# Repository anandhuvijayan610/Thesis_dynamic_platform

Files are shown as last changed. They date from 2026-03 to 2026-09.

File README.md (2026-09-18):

# Dynamic Platform — a camera-guided ball balancing and juggling robot

A four-arm parallel platform that balances and juggles a 40 mm ball. A camera **underneath a
transparent plate** tracks the ball, a PC works out the plate tilt and height that bring it back to
the target, and a Teensy 4.0 turns that pose into step pulses for four geared stepper motors.

Built for a thesis at Deggendorf Institute of Technology, Campus Cham, on top of Tobias Kuhn's
open-source [HighPrecisionStepperJuggler](https://github.com/T-Kuhn/HighPrecisionStepperJuggler).

## Demo

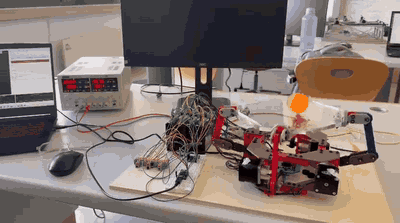
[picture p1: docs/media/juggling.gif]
The machine juggling: the plate throws the ball and catches it, cycle after cycle


**Juggling.** The plate throws the ball and catches it, over and over.

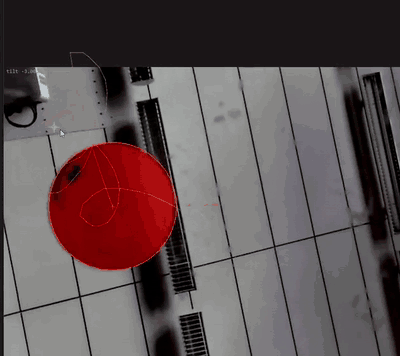
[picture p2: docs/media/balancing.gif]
The camera's view of the plate with the ball tracked in red and the green cross marking the commanded position


**Holding a target.** What the camera under the plate sees. The ball is outlined in red and the
**green cross is the commanded position** — the loop keeps the ball on it. Clicking the video in the
app moves the target.

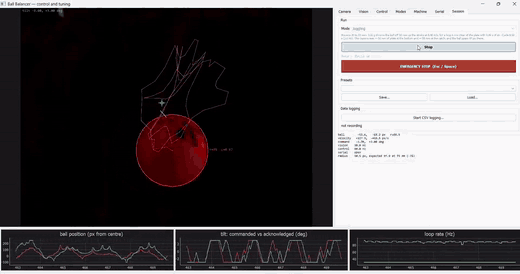
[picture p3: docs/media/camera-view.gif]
The control window during a juggle, with live plots of ball position, tilt and loop rate


**Juggling from the camera view.** The same juggle inside the control app, with the live plots
running: ball position, commanded versus acknowledged tilt, and loop rate.

## Run the demo

You need the machine powered up, the camera plugged in, and the
[firmware](docs/firmware.md) already on the Teensy. Note the Teensy's COM port first.

### The quick way — PyQt5 app

```bash
cd pyballbalancer
pip install -r requirements.txt
python main.py
```

Then, in the window:

1. **Serial** tab → *Refresh ports* → pick the `COMx` → *Connect*
2. **Machine** tab → *Go to ORIGIN* — the plate should rise and sit level
3. Place the ball on the plate
4. **Session** tab → choose **Balancing** → *Start control*

Try **Juggling** on the Session tab once balancing holds. Click the video to move the target.

- **Stop:** `Esc` or `Space`, or the red button.
- **Close the window normally** rather than killing the process — closing parks the plate level. If
  the plate is left leaning, run `python park.py`.

### The other way — Unity app

Open the project in **Unity 2019.2.23f1**, load
`Assets/HighPrecisionStepperJuggler/MainScene.unity`, set the serial port and strategy program in
the Inspector, press **Play**, then **Space** to arm. Full steps: [docs/unity-app.md](docs/unity-app.md).

## Two hosts, one machine

There are **two separate programs** that can drive this machine, and they share only the hardware
and the firmware:

| | [PyQt5 app](pyballbalancer/README.md) | [Unity app](docs/unity-app.md) |
|---|---|---|
| Language | Python 3 | C# (Unity 2019.2.23f1) + a C++ OpenCV plugin |
| Camera frame | 640 × 480 landscape | 480 × 640 portrait |
| Gain units | degrees per **pixel** | degrees per **millimetre** |
| Tuning | live, from GUI tabs | Inspector values in the scene |

**Do not copy tuning from one to the other.** Different frame orientations, different units,
different calibration — the same number means something else in each. Only one of them can hold the
serial port, so close one before starting the other.

## Documentation

| Page | What is in it |
|---|---|
| [docs/hardware.md](docs/hardware.md) | Parts, wiring, DM542T switch settings, power |
| [docs/firmware.md](docs/firmware.md) | Uploading to the Teensy, the wire protocol, key constants |
| [pyballbalancer/README.md](pyballbalancer/README.md) | The PyQt5 app in full: modes, calibration, tuning, every script |
| [docs/unity-app.md](docs/unity-app.md) | Unity setup, strategy programs, keyboard controls, calibration |
| [docs/camera-and-motion.md](docs/camera-and-motion.md) | Why the camera's field of view limits the design, and the throw physics |
| [docs/troubleshooting.md](docs/troubleshooting.md) | Known issues, traps, and what to check when nothing moves |
| [docs/repository.md](docs/repository.md) | Folder layout, Git LFS notes, thesis tooling |

## Licence and credits

Firmware, Unity application, camera plugin and the original paper are by **Tobias Kuhn** — see
[HighPrecisionStepperJuggler](https://github.com/T-Kuhn/HighPrecisionStepperJuggler) and the related
[Octo-Bouncer](https://www.electrondust.com/2020/03/01/the-octo-bouncer/), MIT licence
([LICENSE](HighPrecisionStepperJuggler-master/LICENSE)).

The hardware rebuild, firmware fixes, Unity extensions, the PyQt5 application and all calibration in
this repository are by **Anandhu Vijayan**.

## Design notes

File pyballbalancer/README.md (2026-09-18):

# Ball Balancer — PyQt5 control application

*One of the two host applications in this project. See the
[main README](../README.md) for the machine as a whole, and
[docs/hardware.md](../docs/hardware.md) / [docs/firmware.md](../docs/firmware.md) for what this
talks to. The Unity host is separate: **do not copy tuning between them**.*

A replacement for the Unity host application: camera capture, ball detection,
tilt control, serial link to the microcontroller, and live tuning of every
parameter without restarting.

```
pip install -r requirements.txt
python main.py
```

## Modules

| file | responsibility |
|---|---|
| `params.py` | every tunable value, declared once in `SPECS`; the GUI is generated from it |
| `camera.py` | `CameraWorker` — capture thread, applies UVC controls, runs detection |
| `vision.py` | two interchangeable detectors, both returning centre-frame coordinates |
| `control.py` | velocity estimation, PID, mirror-law tilt, the fixed-rate `ControlLoop` |
| `serial_io.py` | `SerialWorker` — owns the port, coalesces writes, applies the level trim, parses telemetry |
| `machine.py` | kinematics: plate pose → four arm angles → the firmware's wire format |
| `machine_panel.py` | the Machine tab: manual moves, levelling at the working height, bring-up tests |
| `modes.py` | the session modes and juggling supervision; owns height, move time and cadence |
| `optics.py` | camera window and throw physics, validated against the rig |
| `datalog.py` | buffered CSV recorder |
| `widgets.py` | parameter editors and the video view |
| `gui.py` | `MainWindow` — assembles panels, owns the workers, routes signals |
| `main.py` | entry point |

Threads: capture, control and serial each own one. The GUI thread only paints.
Anything crossing a thread boundary goes through a Qt signal, except the
parameter store, which is guarded by a lock because both worker threads read it.

## The firmware protocol

The Teensy runs the SineStepper sketch, and its protocol is not a command
language. Each line is colon-separated doubles, six per move batch, with up to
100 batches concatenated:

```
PC  -> MCU   <marker>:<a0>:<a1>:<a2>:<a3>:<move_time>
             PING
MCU -> PC    PONG
```

`marker` is `11.0 x batch_number`, counting from one, and a batch whose marker
does not match is skipped. `a0..a3` are the four arm angles in **radians**, as
a **difference from the origin pose**, because the firmware treats its power-on
position as zero. `move_time` is in seconds and is clamped up to a 0.05 s floor.

There is no `HOME` and no `STOP`. Levelling and the emergency stop are both a
move to the origin pose — the safe state has to be commanded, not requested.
`PING` is the exception: it is answered with `PONG` before the line reaches the
parser, so it is the only liveness check available.

`machine.py` turns a plate pose — height in metres, two tilts in degrees — into
those four angles, and `machine.serialize()` builds the line. Nothing else in
the application knows the wire format.

**A malformed line fails silently.** The firmware's `strtok`/`atof` parse yields
zero batches and it does nothing at all, so a protocol mismatch is
indistinguishable from dead motors. If the plate will not move, PING first.

**Pose commands are coalesced.** If the control loop outruns the port, only the
newest pose is sent. A stale tilt is worse than none, and a growing backlog
would show up as the plate lagging the ball by a variable amount.

## If the plate looks tilted

The motors hold whatever pose they were last given. Anything that stops without
tidying up — a diagnostic script that ends mid-sequence, a window that is killed
rather than closed — leaves the plate at the last tilt the control loop asked
for. It looks exactly like the levelling trim having drifted, and it is not.

```
python park.py
```

That commands the calibrated level origin and prints the line it sent beside the
line an untrimmed plate would get. The trim is working if the four arm angles
differ from each other; if all four are identical, the trim has been lost.
**Close the window rather than killing it** — `closeEvent` parks the plate on
the way out, and a force-kill skips it.

## Settled calibration

These are on this machine, found by adjustment until the ball sits still in the
middle of the plate and does not roll:

```
arm pairing     0+2 / 1+3                 motors confirmed opposite by eye
working origin  20 mm above the mechanical dead position
level trim      X -0.40, Y -0.40 degrees, levelled at 35 mm (mac_trim_height)
axis mapping    swap/invertX/invertY all off
gains           kp 0.02  ki 0.10  kd 0.04 per axis,  integral clamp 20,
                scaled with ball radius (reference radius 111 px)
limits          max tilt 3 deg, max tilt rate 25 deg/s, command rate 100 Hz
camera          exposure -8, gain 120
detection       H 0..20, S>=150, V>=15, kernel 7, min fill 0.80, min circularity 0.30
```

The trim and gains have been re-found more than once as the rig changed: an
earlier set (trim X -1.30 / Y +0.35, kp 0.05 / kd 0.07) predates levelling at
the working height and is superseded. The values above are the shipped defaults
in `params.py`.

Two things about the trim are easy to get wrong. It is **per pairing** --
changing which motor each tilt drives invalidates it -- and it is **per
height**: these differ by about 1.5 degrees from the values a spirit level
gives at the origin, because the linkage carries a residual slope between the
origin and the 40 mm the controller runs at. Levelling at the origin is not
enough; the definition that matters is where the ball stays.

The integral term is what removes that slope, and `pid_i_clamp` is the part
that makes it possible: it bounds the tilt the integral may ask for at
`Ki x clamp`. At the old clamp of 2.0 that ceiling was 0.2 degrees with
Ki=0.1, far short of the degree or so a real slope needs, so raising Ki alone
achieved nothing. Simulated against a 1.4 degree slope, ki=0 leaves 28 mm of
standing offset and ki=0.1 with clamp 20 leaves none, halving the peak
excursion as well. Ki=0.8 is unstable, so there is plenty of margin.

**Adjusting until the ball stays beats measuring the slope and correcting it.**
Measuring it from the ball's drift open-loop was not reproducible here: the
same trim read `(+334, +748)` on one run and `(-677, -710)` on the next, sign
flipped on both axes, because the ball is placed by hand and is still moving
when the reading starts. Fitting acceleration instead of velocity removes the
dependence on that initial speed and is exact without noise, but over the short
arc the ball survives it is far too noisy to act on.

## Levelling the plate

The plate does not sit level when all four arms are at their origin — arm
length tolerances and how the joints seated during assembly leave a standing
tilt, on this rig along the X pair. `mac_trim_x` and `mac_trim_y` cancel it.

Set them from the Machine tab, with a spirit level on the plate: the nudge
buttons move the trim and immediately re-send the origin pose, so the plate is
adjusted by eye. Do X first — tilting one pair changes how level the other
looks. The offset is then added to *every* commanded tilt, the control loop's
included, so a level plate here means the controller's zero is the real zero
rather than a standing bias it has to fight.

It is applied in exactly one place: `SerialWorker`, the funnel every wire-bound
pose passes through. Several call sites build poses — the Machine panel, the
mode runner, the emergency stop — and applying it at each would eventually miss
one or double it somewhere.

**It is deliberately not folded into `ORIGIN_ANGLES`.** `serialize()` subtracts
that constant from every target, so a trim added there too would cancel itself
out and the plate would never move. The Unity host documents the same trap for
its own origin offset.

**Level where the loop works, not at the origin.** The linkage carries a
residual slope that changes along its travel, so the trim is a property of the
*height* as much as of the machine -- here the two differ by about 1.5 degrees
between the origin and the working height. The nudge buttons therefore send the
plate to `mac_trim_height` (35 mm above the working origin by default) and
adjust it there, rather than at the origin. A spirit level gets you close; the
definition that matters is that the ball stays put at that height. See
**Settled calibration** above for the shipped values.

Measured on the rig, the origin pose at several trims:

```
trim X      a0       a1       a2       a3
+0.00    0.11941  0.11941  0.11941  0.11941
+0.50    0.13462  0.10415  0.11941  0.11941
+1.00    0.14978  0.08884  0.11941  0.11941
-1.00    0.08884  0.14978  0.11941  0.11941
```

The X pair splits, the Y pair is untouched, and the two directions mirror.

## Exposure decides detection

The single most important setting for detection is the camera exposure, not
the colour gate. Measured on this rig at exposure -6 with gain 110, **55% of
the ball was clipped to pure white** -- V=255, saturation 0, hue meaningless.
There is no colour left in a clipped pixel, so no threshold can recover it: the
mask became a crescent of the ball's shaded side, and the centre of that
crescent sat **35 px (7 mm) away from the ball's true centre**, consistently,
in the direction of the highlight. A steady bias like that does not average
out; the controller simply chases the wrong place.

Widening the gate cannot fix it, and the sweep says so plainly -- every
combination of hue and saturation gave 35-36 px. Nor can geometry: fitting a
circle to the crescent's boundary (algebraic and RANSAC both tried) reached
28.7 px at best, because the mask was eroded all round rather than merely cut
on one side.

At exposure **-8 with gain 60** nothing clips, and the numbers change
completely:

| | before | after |
|---|---|---|
| median centre error | 35.2 px (7.2 mm) | **0.8 px (0.2 mm)** |
| radius reported | 90 px, true 139 | 97 px, true 100 |
| frame-to-frame jitter | - | 1.1 px |
| live detection rate | 94% | 40 of 40 |

*(The shipped camera setting is now exposure -8 with gain 120, and the value
floor has since been lowered to `V>=15` with a 7 px kernel and a fill gate -- a
floor of 50 was cutting away the ball's shaded half. The measurement above is
kept because it is the evidence for the principle.)*

The gate that suits that image is `H 0..20, S>=150, V>=50`. **Saturation is what
separates ball from background**, and it can be that strict only because the
ball is no longer blown out: 95% of its pixels sit at S=255 while the ceiling
is grey. Value cannot do the separating -- the background reaches V=110 and the
ball starts at V=101 -- which is why the value floor is deliberately loose and
only rejects sensor noise.

**So check for clipping before touching the colour gate.** If the ball's
histogram piles up at V=255, the exposure is the fault and everything
downstream is guesswork.

## Which blob is the ball

A single frame cannot say. A ball whose lit side falls outside the colour gate
breaks into several contours, and background clutter can be rounder than any of
them. `BallTracker` uses continuity between frames instead:

- **Plate region.** Candidates further than `vis_roi_radius` from frame centre
  are discarded outright. The ball is on the plate and the plate is centred, so
  this is the strongest geometric evidence available, and the ball's centre has
  far less travel than that before it clips the frame edge anyway.
- **Trust is earned.** A new candidate must hold within `vis_lock_tol_px` for
  `vis_lock_frames` consecutive frames before it is believed. Until then the
  answer is "no ball", which every caller already treats as wait-and-do-nothing.
- **Then tracked by proximity**, within `vis_gate_px` of the last accepted
  position, with the lock dropped after `vis_gate_frames` consecutive misses so
  a ball that is picked up and put back somewhere else is found again.

The cold-start rule is the subtle one: it picks the candidate nearest the
centre of the plate, **not** the largest. Taking the largest is what latches
onto background, and once latched the proximity gate defends that choice
forever, because something that never moves always looks like the same thing,
still nearby. The lock has to be earned before it is trusted, not assumed and
then defended.

Detection is therefore stateful, and one frame can never produce a ball. Call
`VisionProcessor.reset()` when a run starts; the GUI does this on arming so a
lock earned while idle is not inherited.

**Tune the colour gate on a frame captured through this application**, not on a
raw `cv2.VideoCapture` grab. The app pushes saturation, contrast and gain into
the camera, and those move the whole scene: on a raw capture a plain ceiling
sits well below the saturation floor, while through the app the same ceiling
reaches a median of 64. A gate tuned on the wrong image looks fine in the
measurement and admits half the background in use.

## Which way does the plate push the ball

If a commanded tilt moves the ball the wrong way the loop accelerates it
outward instead of catching it, and the ball leaves every time — which reads as
gains being wrong, or the plate being too aggressive, rather than as a mapping
fault. `ctl_swap_axes`, `ctl_invert_x` and `ctl_invert_y` describe the mapping;
there are eight combinations and trying them by hand costs a ball roll each.

```
python signtest.py            measure and report
python signtest.py --apply    and write the result into the parameters
```

It tilts ±2 deg on each axis and measures the ball's response. Three details
are what make it work on a plate with no rim:

- **Velocity, not position.** Under a constant tilt the ball accelerates, so
  where it ends up after a fixed time depends on where it started. How fast it
  is moving does not.
- **Both directions, differenced.** A plate slightly off level, or a ball
  already drifting, adds the same bias to the + and - legs; subtracting them
  cancels it. A single leg measures the bias as much as the response.
- **A centimetre of travel per leg**, and each tilt is unwound by the opposite
  one for twice as long, which brings the ball back near rest.

It also reports the angle between the two response directions. That must be
near 90 deg: if the two tilt commands act on nearly the same physical
direction, no swap or invert can express the mapping and the fault is the motor
pairing (`machine.MOTOR_ORDER`) instead.

**The plate has no rim, and that is the practical obstacle.** A cardboard
collar or a tape lip around the edge makes this measurement and every tuning
step after it straightforward. Without one the ball may leave mid-measurement —
the tool says so rather than reporting a guess.

## Modes

Five, picked on the Session tab; the numbers live on the Modes tab.

| mode | what it does |
|---|---|
| **Balancing** | holds the ball at the balancing height, indefinitely |
| **Balance then rest** | holds it lively for a while, then softens the gains so it slows and stops in the middle |
| **Balance and juggle** | holds it centred, and throws a hop every few seconds |
| **Juggling** | bounces continuously, four phases per cycle (35 → 51 mm by default) |
| **Juggle routine** | a structured sequence modelled on the Unity host's Full Juggling Demo: warm-up bounces, then walking the target out and back and tracing a small circle, with settling cycles between legs |

### Juggling is supervised

The camera's window is narrow, so a drifting ball is lost long before the plate
runs out of travel. Both juggling modes therefore treat "centred" as something
to keep earning:

- **Throwing only starts** once the ball is within `mod_jug_centre_px` (40 px)
  and slower than `mod_jug_centre_speed` (120 px/s) for `mod_jug_centre_hold`
  (8) consecutive commands.
- **Throwing stops** and the plate falls back to balancing whenever the ball
  drifts beyond `mod_jug_keep_mm` (30 mm) or is unseen for
  `mod_jug_lost_seconds` (0.4 s). The routine also resets its target to the
  centre.
- **While re-centring, the rest gains are swapped in**, which bring the ball in
  faster than the lively juggling gains.
- **If the plate was at the top of a stroke, it comes down over the fall time.**
  Dropping 16 mm in a short balancing move is about 2 g, which pulls the plate
  out from under the ball and throws it again.

### Sizing a hop

**Commanded acceleration does not predict whether the ball leaves the plate on
this machine.** Measured: 30 mm in 0.10 s (1.51 g) separates it, while 20 mm in
0.08 s -- a *higher* 1.57 g -- does not. The short stroke gives the motors too
little time to reach the speed being asked for, so they under-deliver. If the
ball is not leaving the plate, go **bigger and slower**, not faster.

30 mm in 0.10 s is the smallest proven hop, leaving at 0.47 m/s for an 11 mm hop
with about 0.10 s of air; the shipped *Balance and juggle* default is now a
larger 50 mm in 0.11 s (`mod_hop_mm`, `mod_hop_rise`). The plate then holds still at the top for
that airborne time, so the ball lands on a stationary surface rather than a
moving one, and returns down twice as slowly -- the fall throws nothing, so
speed there is only shaking the frame.

**Tilt stays live through every phase, the airborne one included.** The plate
has to be in the right place when the ball comes down, and levelling during the
hop throws away exactly the correction that would put it there.

The Session tab picks a mode and starts it; the Modes tab holds the numbers.

**Balancing** rises once to `mod_balance_height` (30 mm above the working
origin by default) over `mod_rise_time`, waits `mod_settle_time`, then holds
that height and issues a tilt every `mod_balance_move_time`. No tilt is applied
during the climb: the ball has nothing useful to say while the platform is
still moving vertically, and correcting against a rising plate only fights it.

**Juggling** runs a four-phase cycle at that height: a fast rise that throws the
ball, a dwell while it is airborne, a deliberately slower fall, and a dwell at
the bottom. Only the rise needs to beat 1 g; the fall launches nothing, so
speed there is structural excitation for no benefit, and the dwells let the
frame stop ringing between strokes. The panel reports the rise's peak in g, and
says plainly when it is too gentle to lift the ball off the plate. Tilt is
corrected on every phase, including the fall and the bottom dwell, because
those are when the ball is in contact and can actually be rolled toward centre.

**A long move is sent once and then left alone.** The firmware clears its
queued batches and restarts on every line it receives, and each move is a
half-cosine that begins at rest -- so re-sending the same target every control
tick restarts the profile from zero velocity and the plate crawls upward at a
few mm/s while the log looks perfectly healthy. `ModeRunner.command()` returns
`None` to mean "a move is still running, do not interrupt it". That is why the
mode owns the cadence rather than the control loop.

Arming requires an open port. Without one the loop would run and the mode would
advance through its phases with nothing reaching a machine.

## When it looks like nothing is happening

The firmware is built with `VERBOSE_SERIAL_LOGGING` set to `0`. It answers
`PING` with `PONG`, prints a rejection for a batch whose marker is wrong, and
**says nothing else at all** — not for a move it accepted, not for a line it
could not parse. A healthy link is therefore almost entirely silent, and an
empty monitor is the normal state rather than a symptom.

Two scripts settle it without guessing. Nothing else may hold the port while
they run — Windows allows one owner, so close the GUI first:

```
python hwtest.py            bare pyserial: is the board alive?
python hwtest.py --move     ... and does it move?
python workertest.py        the same, through the app's own SerialWorker
python workertest.py --move
```

`hwtest.py` sends a deliberately bad marker, which is the one malformed input
the firmware does complain about — a reply proves the parser is running and
reading our fields, not merely that the cable is plugged in. If `hwtest` passes
and `workertest` fails, the fault is in the application; if both pass and the
plate still does not move, it is past the microcontroller: driver enable, motor
power, or the DM542T wiring.

## Bringing the machine up

The *Machine* tab exists because a control loop cannot be debugged before the
three things under it are known to work, in this order:

1. **Go to ORIGIN** — level, at the working origin. The plate at rest has no
   downward travel -- and the structure interferes near the bottom -- so the
   working origin is parked 20 mm above it (`mac_origin_offset`) to give the
   loop room to move either way.
2. **Height, no tilt** — a pure vertical move proves all four arms are driven,
   wired the same way round, and agree with each other. If the plate skews, the
   fault is mechanical or in `MOTOR_ORDER`, not in the control maths.
3. **Tilt** — one axis at a time, then the sweep. If both axes tip the plate the
   same physical way, `MOTOR_ORDER` in `machine.py` pairs the arms wrongly.

Every button prints the line it sent and the per-motor angle and pulse count
behind it, so a plate that does not move can be diagnosed as bad numbers or bad
motors without reaching for a scope.

## First run

1. **Camera** tab — set the device index. If the picture is dark, raise Gain
   before lengthening Exposure: a long exposure smears a moving ball, and
   motion blur costs more than noise does.
2. **Vision** tab — tick *Show mask* and adjust the HSV range until the ball is
   solid white and nothing else is. Tune with the mask visible; tuning against
   the colour image is guesswork. Untick it when you are done.
3. **Serial** tab — *Refresh ports*, pick the `COMx`, *Connect*. Telemetry
   should start scrolling if the firmware is sending it.
4. **Control** tab — set *Max tilt* low (2–3°) for the first run.
5. **Session** tab — *Start control*. Click the video to move the target.

### Getting the axis signs right

The camera's axes almost never match the plate's first time. With the ball
resting off-centre and the loop running, watch which way the plate moves. Use
*Swap axes*, *Invert X* and *Invert Y* until a ball sitting to the right makes
the plate lift on the right. If the ball accelerates away instead of returning,
a sign is wrong — no amount of gain tuning fixes that, and raising the gain
makes it leave the plate faster.

## Tuning the controller

Start from `Kd`, not `Kp`. A ball on a plate is a double integrator with a
transport delay, and such a plant needs the derivative term to be stable at
all; proportional-only control oscillates with growing amplitude no matter how
small the gain. `simtest.py` demonstrates both cases.

Measured behaviour of an earlier gain pair (`Kp` 0.05, `Kd` 0.07) against the
simulated plant -- the shipped defaults are now softer (0.02 / 0.04), but the
delay trend is the lesson and still holds:

| loop delay | result |
|---|---|
| 15–100 ms | settles, no overshoot |
| 150 ms | still settles, but rings noticeably |
| 200 ms and up | does not settle — re-derive the gains |

The *control* trace on the rate plot is the number that matters here. If it
falls, the delay rises and the gains that were right become wrong.

## Emergency stop

`Esc` or `Space`, or the red button. It disarms the loop, commands 0° and
commands the plate level at the working origin in the shortest move the
firmware accepts. Re-arming with *Start control* clears it. Closing the window
levels the plate before the process exits.

## Tests

```
python selftest.py    # parameters, velocity estimation, PID, mirror law, vision, logging
python machinetest.py # kinematics and the wire format
python modetest.py    # the mode state machine, against an injected clock
python guitest.py     # the real window offscreen: threads, and every button clicked
python simtest.py     # closed-loop simulation against a modelled ball and plate
```

`selftest` and `simtest` need no hardware; `guitest` runs headless. All three
exit non-zero on failure, so they can be wired into a pre-commit hook.

## Every script, at a glance

The application itself is `main.py` plus the modules listed at the top. Everything else is a tool
that does one job, run from this folder. The hardware ones need the serial port to themselves, so
close the GUI first.

| Script | Purpose | Hardware? |
|---|---|---|
| `selftest.py` · `machinetest.py` · `modetest.py` · `simtest.py` | Parameters, vision, kinematics, wire format, mode state machine, closed-loop simulation | no |
| `guitest.py` | Builds the real window offscreen and clicks every button | no |
| `optics.py` | Camera window and throw physics model (also importable) | no |
| `hwtest.py` · `workertest.py` | Is the board alive, and does it move? `--move` also moves the plate | yes |
| `park.py` | Put the plate back on the calibrated level origin | yes |
| `movetest.py` | Presses the Machine tab's buttons for real | yes |
| `signtest.py` · `mappingsearch.py` · `pairingtest.py` | Which way the plate pushes the ball; the axis mapping; which arms pair | yes |
| `autolevel.py` · `centretrim.py` · `backlashtest.py` | Levelling and play, using the ball as the instrument | yes |
| `exposuretest.py` · `heighttest.py` | Exposure that measures the ball at true size; visibility when raised | yes |
| `livetest.py` | The oscillation, with the whole GUI alive around it | yes |
| `unitycheck.py` | Confirms the two hosts agree on **hardware** facts only; reports tuning side by side without judging it | no |

## Notes on two defaults that are not obvious

**`vis_hough_p2` is 16, not the more usual 32.** The transform runs on the
binary mask, whose thinned edges cast far fewer accumulator votes than a grey
image's would. Measured on synthetic balls from 10 to 160 px radius, 32 finds
nothing at any size while 16 finds all of them with no false positives.

**Detection runs on the capture thread, not its own.** The control loop wants
the newest ball position, not every position. Queueing frames to a second
worker would add latency and a backlog to drain. Display is throttled to about
30 Hz independently, so the screen never limits the control rate.

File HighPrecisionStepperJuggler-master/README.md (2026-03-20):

The Arduino folder contains the code for the Teensy 4.0. The Teensy 4.0's job is simple:

- Listen for movement comments on the serial bus
- Generate pulses for the stepper motors

The Unity folder contains the code for the Unity Application. This Application is responsible for:

- Set up the camera (120 FPS 640×480 data stream, gain, exposure, contrast, ISO, saturation) via OpenCV
- Set up Camera Device and getting image stream via OpenCV
- Run Image Processing and get 2D pixel position of ping pong ball
- Get 3D position of ping pong ball using the results of above-mentioned image processing
- Calculate ball velocity
- Use ball position and velocity in PID/Analytical control code to calculate correction-tilt of plate
- Execute Inverse Kinematic code to figure out how much each motor needs to rotate in order to get the plate to a certain height with a     specific tilt.
- Send result of IK calculation to the microcontroller via serial interface
- Render machine position and movements
- Render image processing data
- Render graph showing several data streams

The UVCCameraPlugin folder contains the C++ code for the camera plugin. This is a Unity plugin. All the OpenCV code is being executed in here.

# Important
You need to download openCV 4.2 and get the `opencv_world420.dll` from the build folder and put it inside Plugins/UVC Camera Plugin next to `UVCCameraPlugin.dll`. If you don't do that you'll get below error message on play:

```
Plugins: Failed to load 'Assets/Plugins/UVC Camera Plugin/UVCCameraPlugin.dll' because one or more of its dependencies could not be loaded.
```

Also, you need to use Unity Editor version 2019.2.6f1. It won't run with newer versions.

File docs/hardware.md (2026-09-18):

# Hardware setup

### Parts

| Part | Detail |
|---|---|
| Microcontroller | Teensy 4.0 |
| Stepper drivers | 4 × StepperOnline **DM542T** |
| Motors | 4 × NEMA17 **17HS19-1684S-PG5** — 1.8°/step, **5.18:1** planetary gearbox, 1.68 A/phase |
| Power | 35 V / 8 A supply; **XL4016** buck converter for the 5 V rail |
| Linkage | 4 arms, `L1 = 89 mm`, `L2 = 80 mm`, plate joints 299 mm apart, `Q = 70.023 mm` |
| Camera | UVC USB camera, 60.41° horizontal FOV, mounted **below** a transparent plate |
| Ball | 40 mm diameter (radius 20 mm) |

Datasheets for all of these are in [`datasheets/`](../datasheets/); CAD is in [`Design/`](../Design/)
and [`stl files/`](../stl%20files/).

### Wiring (Teensy → DM542T)

The finalised, working connection diagram:

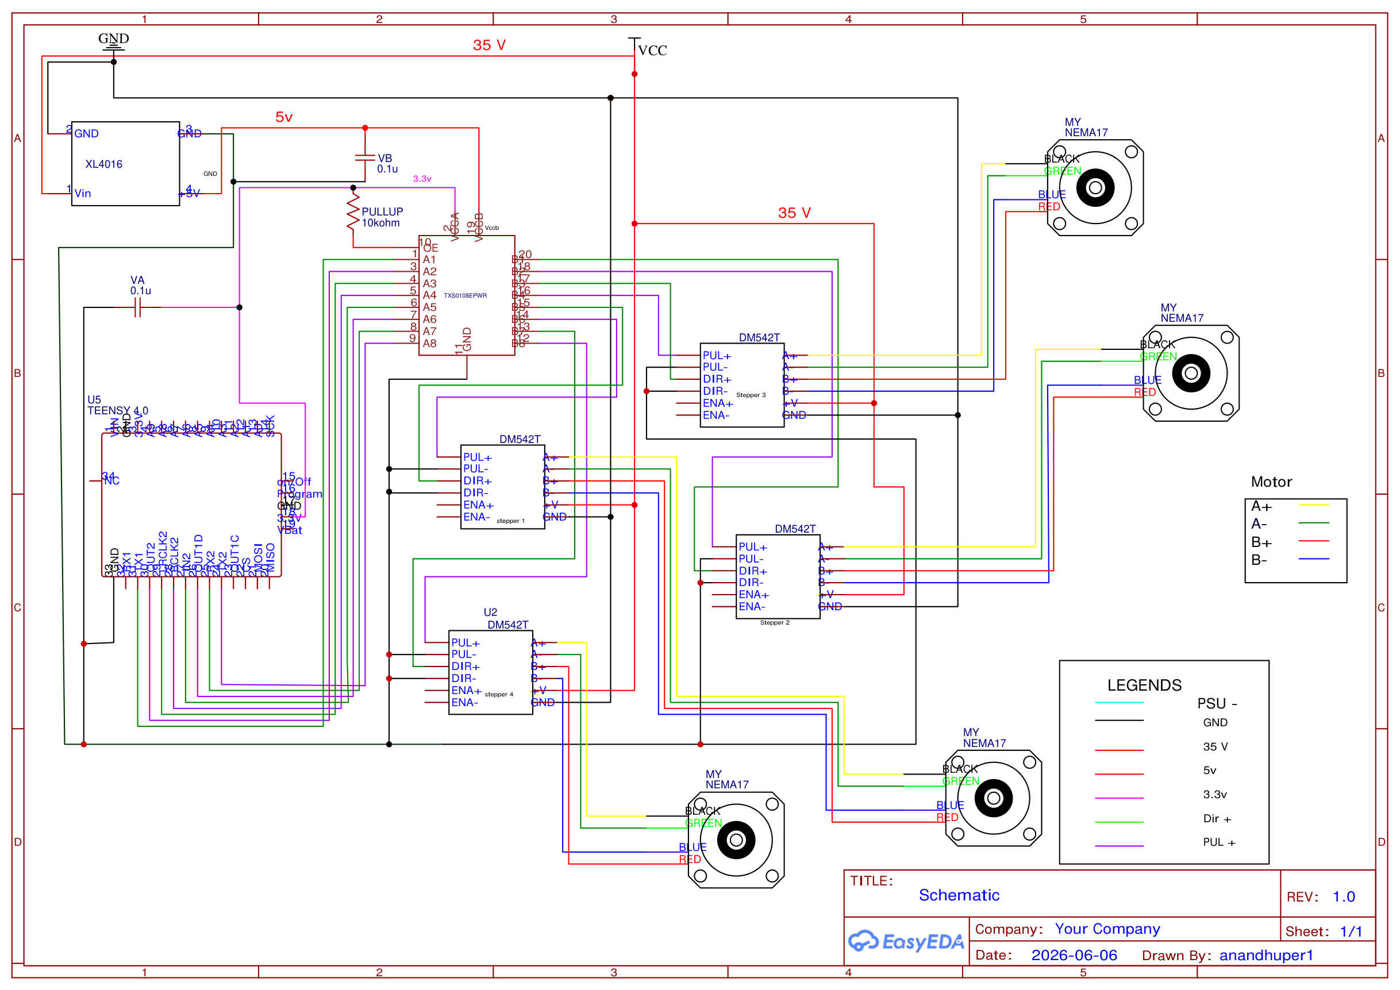
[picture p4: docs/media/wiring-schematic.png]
Finalised wiring schematic: Teensy 4.0 through a TXS0108E level shifter to four DM542T drivers and four NEMA17 motors, with an XL4016 buck converter making the 5 V rail


*Click for the vector PDF ([media/wiring-schematic.pdf](media/wiring-schematic.pdf)). Drawn in
EasyEDA; the source is also kept in
[`my_documents/connection diagrams/`](../my_documents/connection%20diagrams/).*

Reading it: the main rail feeds all four `DM542T` `+V` inputs and an **XL4016** buck converter that
makes **5 V**; the **TXS0108E** shifts the Teensy's eight STEP/DIR lines up to that 5 V rail
(`VCCA` 3.3 V, `VCCB` 5 V, `OE` held high through a 10 kΩ pull-up, 0.1 µF on each supply). Motor
coils follow the legend — **A+ yellow, A− green, B+ red, B− blue**.

Pin numbers are fixed in the firmware's `Constants.h`:

| Motor | STEP pin | DIR pin |
|---|---|---|
| 1 | 6 | 5 |
| 2 | 2 | 1 |
| 3 | 4 | 3 |
| 4 | 8 | 7 |

Common-cathode wiring: `PUL-` and `DIR-` to GND, the `+` inputs driven from the Teensy through the
level shifter, `ENA` left unconnected (enabled).

> **Signal levels.** The Teensy is a 3.3 V part and the DM542T inputs are optocouplers specified for
> 5 V, so the **TXS0108E is fitted** and carries all eight STEP/DIR lines up to the 5 V rail. During
> bring-up the lines were driven straight from the Teensy at 3.3 V for a while, which under-drives
> the optos; the shifter is the finished arrangement. The TXS0108E is an auto-direction transceiver
> with weak drive, so if the drivers ever behave as though they are missing pulses at speed, a
> stronger 5 V buffer — a 74HCT541, or one NPN transistor per line — is the fix to reach for.

### DM542T DIP switches

| Setting | Switches | Value |
|---|---|---|
| Microstepping | SW5 ON, SW6 ON, SW7 OFF, SW8 ON | **1/16 → 3200 pulses per motor rev** |
| Current | SW1 ON, SW2 OFF, SW3 ON | 1.36 A RMS / 1.91 A peak |
| Standstill | SW4 OFF | current halved at rest |

**The microstep setting and the firmware must agree.** `PULSES_PER_REV` in `Constants.h` is
`200 × microsteps × 5.18` = `200 × 16 × 5.18` = **16576**. If you change the DIP switches, change
that constant and re-upload, or every move produces the wrong pulse count and the motors stall.
Never change DIP switches or unplug a motor with the driver powered.

The firmware that drives this hardware is documented in [firmware.md](firmware.md).

---

[← Back to the main README](../README.md) · [Hardware](hardware.md) · [Firmware](firmware.md) · [PyQt app](../pyballbalancer/README.md) · [Unity app](unity-app.md) · [Camera & motion](camera-and-motion.md) · [Troubleshooting](troubleshooting.md) · [Repository](repository.md)

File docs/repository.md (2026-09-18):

# Repository layout and housekeeping

```
Thesis/
├── pyballbalancer/                  Host A: PyQt5 control application        → its own README
├── HighPrecisionStepperJuggler-master/
│   ├── Arduino/HighPrecisionStepperJuggler/   Teensy 4.0 firmware (used by BOTH hosts)
│   ├── Unity/HighPrecisionStepperJuggler/     Host B: Unity project
│   ├── Unity/ScriptableRenderPipeline-6.9.1/  HDRP package the Unity project depends on
│   ├── UVCCameraPlugin/                       C++ source of the Unity camera plugin (OpenCV)
│   ├── Latex/                                 Original author's paper source
│   └── LICENSE                                MIT, Tobias Kuhn
├── codes/                           Standalone Teensy test sketches and a Python env check
├── tools/                           Scripts that build the thesis figures and draft document
├── Design/                          Fusion 360 models and arm drawings (.f3d, .pdf)
├── stl files/                       Printable parts (.stl, .3mf) and the full assembly (.step)
├── datasheets/                      Teensy, DM542T, NEMA17, buck converters, level shifter
├── my_documents/                    Wiring diagrams, photos, screen recordings
├── log files/                       Captured Editor/balancing logs and calibration CSV
├── Thesis Report/                   Thesis document — local only, gitignored and not published
└── campus_cham_leitfaden_abschlussarbeiten_en.pdf   University thesis guidelines
```

---

## Working with this repository

- **Git LFS is required.** Binary assets such as the Unity DLLs are stored with LFS. Run
  `git lfs install` before cloning, or those files arrive as small pointer text files.
- **Unity's `Library/` folder is tracked** and Unity rewrites parts of it, along with some `.mat`
  files, whenever the editor is open. Close Unity before committing to keep that churn out of the
  history.
- **`Thesis Report/` is deliberately not in the repository.** It was once committed as a broken
  gitlink; it is now gitignored, so the unfinished report stays on the local machine and is never
  published. A fresh clone will not have that folder at all.
- **Low commit memory breaks Git LFS on Windows.** If `git add` fails with a Go
  `out of memory allocating heap arena map` error, close Unity (or enlarge the page file) and retry.
- **`.mcp.json`** configures an Overleaf MCP server for editing the thesis. It reads
  `OVERLEAF_PROJECT_ID` and `OVERLEAF_GIT_TOKEN` from the environment and contains no secrets.

---

## Thesis tooling

| Script | Output |
|---|---|
| [`tools/gen_figs.py`](../tools/gen_figs.py) | IK geometry, sine motion profile and camera FOV diagrams |
| [`tools/gen_block.py`](../tools/gen_block.py) | System block diagram (`fig_block.png`) |
| [`tools/make_thesis.py`](../tools/make_thesis.py) | Rebuilds the draft `.docx` from the figures (`python-docx`; set `THESIS_DIR` / `FIG_DIR`) |
| [`codes/test_setup.py`](../codes/test_setup.py) | Confirms the Python / OpenCV / NumPy environment |

---

[← Back to the main README](../README.md) · [Hardware](hardware.md) · [Firmware](firmware.md) · [PyQt app](../pyballbalancer/README.md) · [Unity app](unity-app.md) · [Camera & motion](camera-and-motion.md) · [Troubleshooting](troubleshooting.md) · [Repository](repository.md)

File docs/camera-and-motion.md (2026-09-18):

# Camera field of view, and the motion physics

## The camera: why field of view governs everything

This is the constraint that shaped most design decisions on this rig, for both hosts.

The camera looks up through the transparent plate. Its distance to the plate is **67.95 mm with the
plate at the mechanical dead position**, and it grows with plate height, so **raising the plate
widens the view**. The ball is large for how close the camera is: at 50 mm above the working origin
its image is ~175 px across in a 480 px axis.

| Height above working origin | Camera distance | mm per pixel | Ball diameter (px) | Room for the ball's centre before it clips (480 px axis) |
|---|---|---|---|---|
| 0 mm | 88 mm | 0.15 | ~271 | ±15 mm |
| 35 mm | 123 mm | 0.20 | ~196 | ±29 mm |
| 50 mm | 138 mm | 0.23 | ~175 | ±35 mm |
| 70 mm | 158 mm | 0.26 | ~153 | ±44 mm |

*(The working origin is 20 mm above the dead position. Figures use the 60.41° FOV over 640 px and a
20 mm ball radius.)*

Consequences:

- **Detection precision is not the limit; the field of view is.** A pixel is a quarter of a
  millimetre, while ball errors are tens of millimetres.
- **A clipped ball is measured wrongly without any error being raised.** When the ball crosses the
  frame edge the blob becomes a crescent, and its centre is reported **pulled toward the middle** —
  by up to ~5.6 mm when a third of the disc is cut off.
- **Keep targets and juggling well inside the window.** That is why both hosts' juggling modes stop
  throwing and re-centre past 30 mm. Targets at ±40 mm (as in the original Full Juggling Demo)
  leave the ball clipped a large fraction of the time.
- **Exposure matters more than the colour gate.** An over-exposed ball clips to white, loses its
  colour and is detected as a crescent. Fix exposure before touching thresholds.

---

## Motion physics worth knowing

- **Half-cosine moves.** Peak plate acceleration is `π²·A / (2·T²)` for stroke `A` over time `T`.
- **The ball separates part way up, not at the top.** It leaves the plate when the plate's
  deceleration exceeds 1 g, and its exit speed is `v_peak · √(1 − (g/a_peak)²)`.
- **Stroke speed is capped by the step-rate ceiling.** Plate speed is `π·A / 2T`, and the ~25 kHz
  pulse ceiling forces `T` to grow with `A`. Feasible strokes therefore all top out around the same
  exit speed. A shorter, faster stroke buys peak **acceleration**, which is what decides separation.
- **Tilt only moves a ball that is on the plate.** While the ball is airborne tilt does nothing, so
  the contact phases of a juggle are where the steering happens.
- **A juggling cycle's timing sets the control rate.** Unity's `MachineController` adds a 50 ms
  margin after every batch it sends, which caps how often a correction can land.

---

## Motion physics worth knowing

- **Half-cosine moves.** Peak plate acceleration is `π²·A / (2·T²)` for stroke `A` over time `T`.
- **The ball separates part way up, not at the top.** It leaves the plate when the plate's
  deceleration exceeds 1 g, and its exit speed is `v_peak · √(1 − (g/a_peak)²)`.
- **Stroke speed is capped by the step-rate ceiling.** Plate speed is `π·A / 2T`, and the ~25 kHz
  pulse ceiling forces `T` to grow with `A`. Feasible strokes therefore all top out around the same
  exit speed. A shorter, faster stroke buys peak **acceleration**, which is what decides separation.
- **Tilt only moves a ball that is on the plate.** While the ball is airborne tilt does nothing, so
  the contact phases of a juggle are where the steering happens.
- **A juggling cycle's timing sets the control rate.** Unity's `MachineController` adds a 50 ms
  margin after every batch it sends, which caps how often a correction can land.

---

[← Back to the main README](../README.md) · [Hardware](hardware.md) · [Firmware](firmware.md) · [PyQt app](../pyballbalancer/README.md) · [Unity app](unity-app.md) · [Camera & motion](camera-and-motion.md) · [Troubleshooting](troubleshooting.md) · [Repository](repository.md)

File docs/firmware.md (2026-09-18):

# Firmware — Teensy 4.0

Location: [`HighPrecisionStepperJuggler-master/Arduino/HighPrecisionStepperJuggler/`](../HighPrecisionStepperJuggler-master/Arduino/HighPrecisionStepperJuggler/)

The Teensy's job is deliberately simple:

- Listen for movement commands on the serial bus
- Generate pulses for the stepper motors, using a sine-profile pulse generator (`SineStepper`) driven
  from a hardware timer interrupt

### Uploading

1. Install the Arduino IDE with **Teensyduino**.
2. Open `HighPrecisionStepperJuggler.ino`, select **Teensy 4.0**, and set **USB Type: Serial**.
3. Upload. The board then listens on USB serial. The `921600` baud is nominal, since Teensy USB
   serial ignores the baud rate.

Connecting to the port does **not** reset a Teensy, and the motors' power-on position is their zero.
Power the machine up with the plate resting in its mechanical dead position.

### Wire protocol

Each line sent to the board holds one or more move batches of six colon-separated numbers, with up
to 100 batches concatenated:

```
PC  → MCU   <marker>:<a0>:<a1>:<a2>:<a3>:<move_time>[:<marker>:...]
            PING
MCU → PC    PONG
```

| Field | Meaning |
|---|---|
| `marker` | `11.0 × batch number`, counting from 1. A batch whose marker does not match is skipped. |
| `a0 … a3` | The four arm angles in **radians**, measured from the **power-on pose**. |
| `move_time` | Seconds. Anything below **0.05 s** is raised to 0.05 s. |

Things the protocol does not do, which catch people out:

- **There is no HOME or STOP command.** Parking and emergency stop are both ordinary moves to the
  origin pose.
- **A malformed line fails silently.** The firmware parses nothing and does nothing, which looks
  exactly like dead motors. If the plate will not move, send `PING` first.
- **A new line cancels the running move.** Every move is a half-cosine that starts from rest, so
  re-sending the same target on every control tick restarts the profile each time and the plate
  crawls. A long move must be sent once and then left alone.
- **It is almost silent by design.** With `VERBOSE_SERIAL_LOGGING 0` the board answers `PING` and
  reports a bad marker, and says nothing else, not even for an accepted move.

### Key constants (`Constants.h`)

| Constant | Value | Why |
|---|---|---|
| `PULSES_PER_REV` | 16576 | 1/16 microstepping × 5.18 gearbox. Must match the DIP switches. |
| `MOVE_DURATION` | 0.05 s | Minimum accepted move time |
| `TIMER_US` / `FREQUENCY_MULTIPLIER` | 10 µs / 1e-5 | Must describe the same tick. A mismatch makes every move slower than requested. |
| Peak step rate | ~25 000 steps/s | One toggle per two 10 µs ticks. This is what limits stroke speed. |
| `MAX_NUM_OF_MOVEBATCHES` | 100 | Batches per line |
| `VERBOSE_SERIAL_LOGGING` | 0 | Set to 1 only while bringing up the link. At control rates it adds latency. |

[`codes/`](../codes/) holds bare STEP/DIR test sketches (`motorTest`, `allmotor`, `fixedmove`, …) for
checking drivers and motors without the full firmware.

Both host applications speak this protocol; neither replaces it.

---

[← Back to the main README](../README.md) · [Hardware](hardware.md) · [Firmware](firmware.md) · [PyQt app](../pyballbalancer/README.md) · [Unity app](unity-app.md) · [Camera & motion](camera-and-motion.md) · [Troubleshooting](troubleshooting.md) · [Repository](repository.md)

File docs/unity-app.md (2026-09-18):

# Unity application — setup and use

Location: [`HighPrecisionStepperJuggler-master/Unity/HighPrecisionStepperJuggler/`](../HighPrecisionStepperJuggler-master/Unity/HighPrecisionStepperJuggler/)

The Unity application is responsible for:

- Setting up the camera (120 FPS stream, gain, exposure, contrast, saturation) and receiving images, via OpenCV
- Running image processing to get the 2D pixel position and radius of the ball
- Getting the 3D position of the ball from those results (radius → distance from the camera)
- Estimating ball velocity, using a small least-squares fit solved by gradient descent
- Using ball position and velocity in the PID or analytical controller to compute the correction tilt
- Running the inverse kinematics that turn a plate height and tilt into four motor angles
- Sending the result to the microcontroller over serial
- Rendering the machine, the image-processing output, and live telemetry graphs

[`UVCCameraPlugin/`](../HighPrecisionStepperJuggler-master/UVCCameraPlugin/) contains the C++ source of
the camera plugin. All the OpenCV code runs inside it.

### Setup

1. **Use Unity Editor 2019.2.23f1.** It is the version recorded in `ProjectSettings/ProjectVersion.txt`.
   Newer versions will not open the project cleanly.
2. **OpenCV runtime.** The camera plugin is built against **OpenCV 4.13.0**.
   `opencv_world4130.dll` must sit next to `UVCCameraPlugin.dll` in
   `Assets/Plugins/UVC Camera Plugin/`. It is committed there already. If it goes missing, copy it
   from the `bin` folder of the OpenCV 4.13.0 Windows release, or you will see:
   ```
   Plugins: Failed to load 'Assets/Plugins/UVC Camera Plugin/UVCCameraPlugin.dll' because one or more of its dependencies could not be loaded.
   ```
3. Open `Assets/HighPrecisionStepperJuggler/MainScene.unity`.
4. In the Inspector, check:
   - **`SerialInterface` → Port Name**: your Teensy's port (currently `COM3`). An empty value or `off` disables serial.
   - **`MachineController` → Machine End Point**: `Real` or `ModelAndReal`. `Model` only moves the
     on-screen twin and nothing reaches the Teensy.
   - **`ImageProcessingInstructionSender` → Strategy Program**: see [Strategy programs](#strategy-programs) below.

### Strategy programs

| Program | Behaviour |
|---|---|
| **BalancingOnly** | Waits for the ball, then balances indefinitely with PID. Start here. |
| **FullJugglingDemo** | The original ~100-stage choreography. It starts striking the ball about 2 s in, so the ball leaving the plate is intended. It asks for more travel than this camera can see — see [camera-and-motion.md](camera-and-motion.md). |
| **SmallJugglingDemo** | Settle, a bounded set of gentle 10 mm bounces, then land. |
| **OscillatingJuggling** | A fixed four-phase clock (rise, dwell, fall, dwell) with PID tilt. With `AimTheThrow` on, the analytical controller aims the rise. It is supervised: past 30 mm it stops throwing and balances the ball back, and resumes once the ball has held within 8 mm and under 25 mm/s for 8 commands. |

### Keyboard controls (Play mode)

| Key | Action |
|---|---|
| **Space** | Arm / disarm the selected strategy program. Arming forces a detection image mode. |
| **O** | Go to working origin |
| **H** | Go to mechanical zero |
| **1 – 9** | Go to height 10 … 90 mm · **0** → 2 mm |
| **Arrow keys** | Small test tilts |
| **M / B** | Next / previous image-processing mode · **N** shows its caption |
| **C** | Measure the camera→plate axis mapping (tilts the plate and watches the ball roll) |
| **P** | Measure delivered tilt and static slope, using the ball as an inclinometer |
| **R** | Search for the correct motor pairing |
| **L** | Toggle ball-position logging |
| **I / X** | Log a ball calibration sample at origin / at max distance |
| **T** | Toggle ball trail · (also sends a single-motor test move) |
| **Y** | Ping the Teensy |
| **F2** | Toggle debug GUI |

The **MachineController Inspector** has buttons for the origin, mechanical zero, test heights and
tilts, a backlash reversal cycle, and **level-trim nudges** (X/Y −/+, reset, re-send origin).

**Ball detection only produces real data in the detection image modes.** Every other mode returns
a placeholder ball. Arming with Space switches mode for you, but if you cycle with M/B while armed
you can blind the controller.

### Current calibration on this rig (Unity host only)

| Setting | Value |
|---|---|
| Motor wiring order | `{0, 2, 1, 3}` |
| Working origin | 20 mm above the mechanical dead position (`OriginHeightOffset`) |
| Level trim | X −0.80°, Y −1.30° (applied at the origin) |
| Axis mapping (scene) | swap ✔, invert X ✘, invert Y ✔ |
| PID | k_p 0.111, k_i 0.555, k_d 0.222 (deg per mm); integral clamp 20° |
| Limits | tilt ±3°, max tilt rate 25°/s (PID only) |
| Balancing move time | 0.06 s |
| Camera | exposure −8, gain 120; frame 480 × 640 portrait |
| Size gate | expected ball radius × 1.25 |
| OscillatingJuggling | 35 → 51 mm; rise 0.05 s, top 0.07 s, fall 0.16 s, bottom 0.14 s |

> **Inspector values override `Constants.cs` and C# field defaults.** Any `[SerializeField]` value
> already saved in `MainScene.unity` wins over the number in code. After changing a default, check
> the scene file too, or Play mode will quietly bring the old value back.

### Reading the Gradient Descent View

The black telemetry panel shows ball history as two traces. **Green is X**, drawn with time running
downward. **Orange is Y**, drawn with time running leftward. The yellow cross is the ball now and
the red cross is the commanded target. The thick bars are 6-sample line fits: where a bar starts is
the position estimate and how steeply it leans is the velocity, and both are what the controllers
use. The short ticks on the top and right edges are the predicted landing point, shown only by
bouncing strategies.

The PyQt application is separate and documented in [../pyballbalancer/README.md](../pyballbalancer/README.md). Do not copy tuning between them — see [the main README](../README.md#two-hosts-one-machine).

---

[← Back to the main README](../README.md) · [Hardware](hardware.md) · [Firmware](firmware.md) · [PyQt app](../pyballbalancer/README.md) · [Unity app](unity-app.md) · [Camera & motion](camera-and-motion.md) · [Troubleshooting](troubleshooting.md) · [Repository](repository.md)

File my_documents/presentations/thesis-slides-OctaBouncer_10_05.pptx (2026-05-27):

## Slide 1

- Intelligent Robotics Lab

Octo-Bouncer : Development of a multi-actuated platform for dynamic object

Student: Anandhu Vijayan
Submission date: September 13
Supervisor: Prof. Dr. Dmitrii Dobriborsci

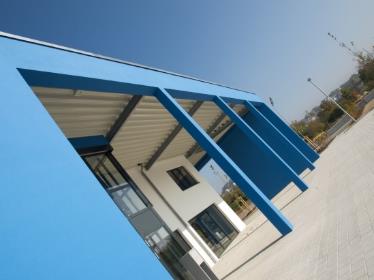
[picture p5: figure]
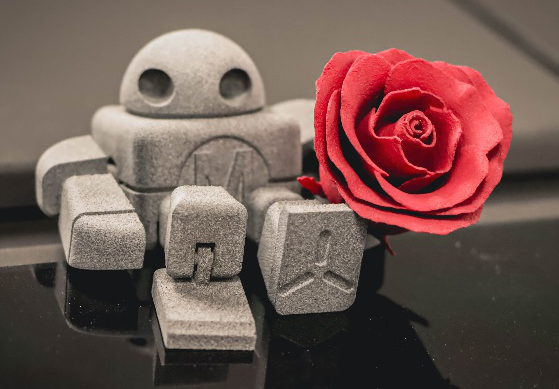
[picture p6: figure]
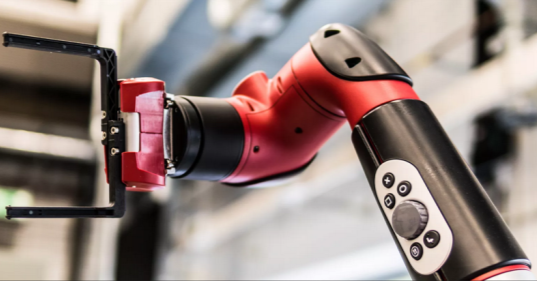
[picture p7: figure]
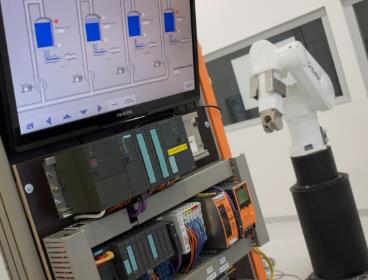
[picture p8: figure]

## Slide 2

Problem definition

- Octo-Bouncer
One of the most challenging problems in a control system is balancing a system. The Octa-Bouncer is a multi-actuated dynamic manipulation system that uses camera-based ball tracking and closed-loop control to generate corrective platform motions that stabilize and influence a bouncing ball.
- Problem statement
  - To develop a real-time robotic platform that can track, predict, and control the motion of a bouncing ball using multiple actuators and visual feedback, ensuring continuous and stable bouncing through closed-loop control.
  - This thesis is relevant because it addresses the challenge of controlling fast, unpredictable dynamic objects using real-time feedback. The system demonstrates important modern robotics skills in computer vision, control, and embedded systems.

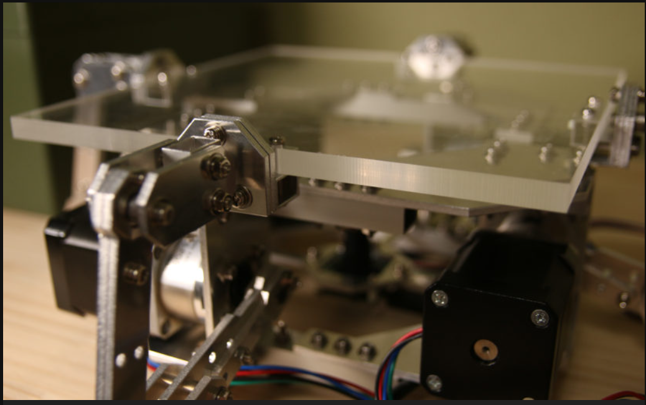
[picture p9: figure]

2

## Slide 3

Problem definition

  - Scope
    - Design and build a multi-actuated platform to control a bouncing ball
    - Implement camera-based ball tracking and real-time closed-loop control
    - Integrate embedded hardware, actuators, and computer vision
    - Evaluate system performance through experiments
  - Deliverables
    - Functional hardware platform
    - Embedded control firmware
    - vision tracking software [if time constraints allows]
    - Control algorithm (e.g., PID) with experimental results
    - Documentation (thesis, CAD, code, and BOM)
  - Limitations
    - No multi-ball manipulation or juggling
    - No advanced AI/ML control unless specified
    - Limited operation in controlled indoor conditions only

3

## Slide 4

Thesis goal

- Main objective
The objective is to build a platform that can automatically keep a ball bouncing by tracking its motion with a camera and adjusting the platform in real time.
- Sub-objectives
  1. Build the hardware platform
  2. Implement camera-based ball tracking
  3. Develop and tune a closed-loop control algorithm
  4. Integrate sensing and actuation in real time
  5. Evaluate system performance through experiments

4

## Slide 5

Plan

Plan for the last 2 weeks

  - Need to find the reason for the short circuit.
  - Rewire everything.
  - Successfully make the connection.
  - After the lens is delivered, need to configure that and make ball detection

5

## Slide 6

Progress

Work completed

- Completed tasks
  - The reason for the short circuit found.
  - Waiting for the level shifter to get delivered.
  - The lens has arrived and it suits the need.

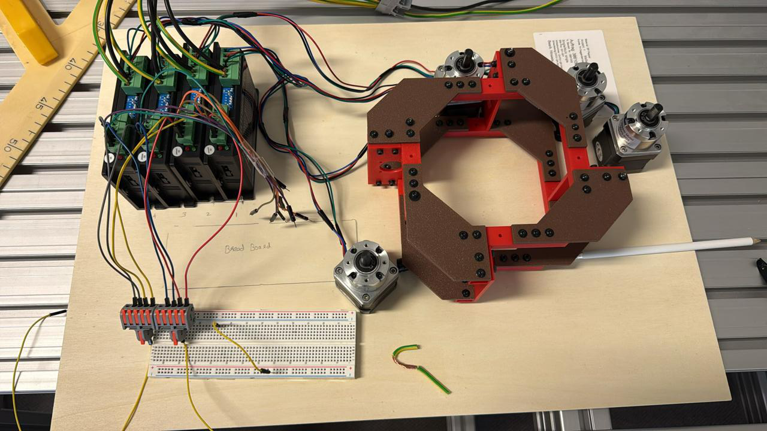
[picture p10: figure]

6

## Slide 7

Plan for the next 2 weeks

Problems Faced:
  - While making the connection the teensy got fried, it was because the teensy was only able to give 3.3v output but the driver required 5 v for the logic side. So this can be tackled by adding a level shifter which converts
3.3v to 5v.

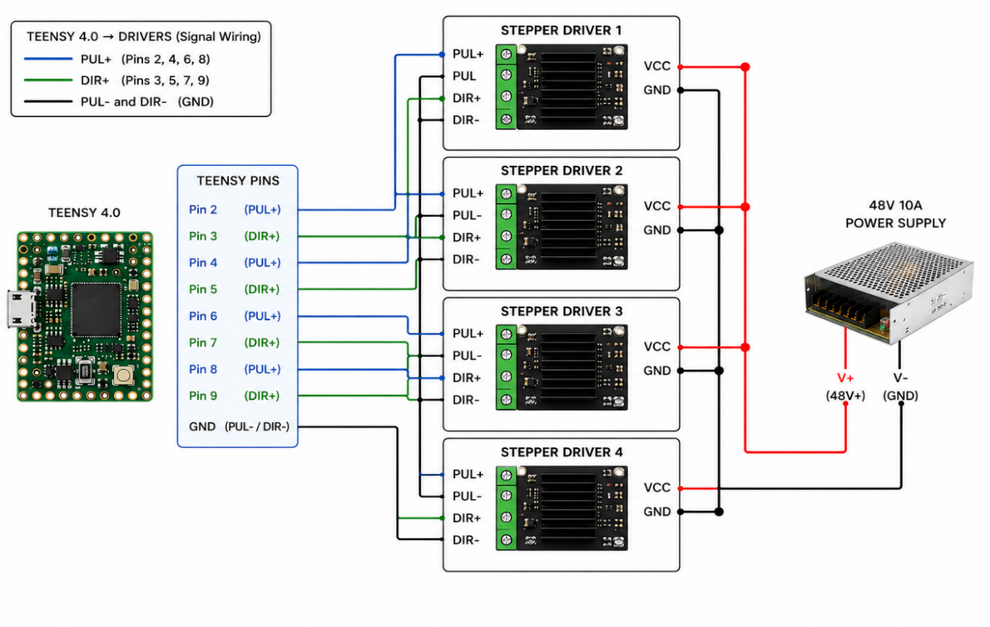
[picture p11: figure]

Connection diagram (which fried the controller)

7

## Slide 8

Plan for the next 2 weeks

Upcoming tasks:
  - Rewire everything.
  - Successfully make the connection.
  - Ball detection using OpenCV, so learn basics of OpenCV and make the ball detection algorithm.

Expected outcomes:
  - Successful connection, ball detection using open CV will be able to start.

8

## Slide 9

Extra

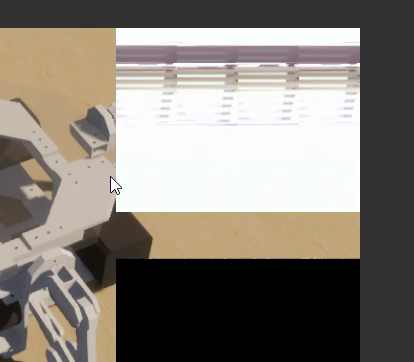
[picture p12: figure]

The feed inside the Unity

The feed inside unity after fixing

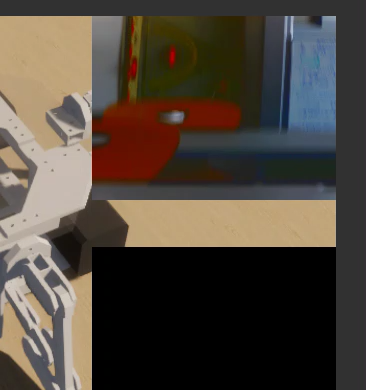
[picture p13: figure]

9

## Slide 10

KONTAKT

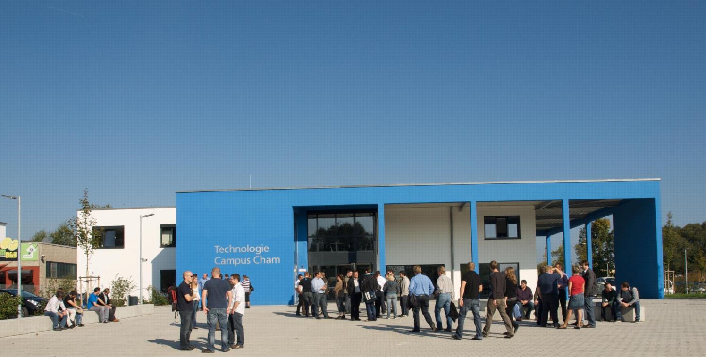
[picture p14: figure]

Herzlichen Dank für Ihr Interesse!

Technologie
Campus Cham
Badstraße 21
93413 Cham
www.tc-cham.de

Prof. Dr. Dmitrii Dobriborsci
Dmitrii.dobriborsci@th-deg.de

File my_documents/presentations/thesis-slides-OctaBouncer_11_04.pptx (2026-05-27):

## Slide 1

- Intelligent Robotics Lab

Octo-Bouncer : Development of a multi-actuated platform for dynamic object

Student: Anandhu Vijayan
Submission date: September 13
Supervisor: Prof. Dr. Dmitrii Dobriborsci


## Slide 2

Problem definition

- Octo-Bouncer
One of the most challenging problems in a control system is balancing a system. The Octa-Bouncer is a multi-actuated dynamic manipulation system that uses camera-based ball tracking and closed-loop control to generate corrective platform motions that stabilize and influence a bouncing ball.
- Problem statement
  - To develop a real-time robotic platform that can track, predict, and control the motion of a bouncing ball using multiple actuators and visual feedback, ensuring continuous and stable bouncing through closed-loop control.
  - This thesis is relevant because it addresses the challenge of controlling fast, unpredictable dynamic objects using real-time feedback. The system demonstrates important modern robotics skills in computer vision, control, and embedded systems.


2

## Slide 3

Problem definition

  - Scope
    - Design and build a multi-actuated platform to control a bouncing ball
    - Implement camera-based ball tracking and real-time closed-loop control
    - Integrate embedded hardware, actuators, and computer vision
    - Evaluate system performance through experiments
  - Deliverables
    - Functional hardware platform
    - Embedded control firmware
    - vision tracking software [if time constraints allows]
    - Control algorithm (e.g., PID) with experimental results
    - Documentation (thesis, CAD, code, and BOM)
  - Limitations
    - No multi-ball manipulation or juggling
    - No advanced AI/ML control unless specified
    - Limited operation in controlled indoor conditions only

3

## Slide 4

Thesis goal

- Main objective
The objective is to build a platform that can automatically keep a ball bouncing by tracking its motion with a camera and adjusting the platform in real time.
- Sub-objectives
  1. Build the hardware platform
  2. Implement camera-based ball tracking
  3. Develop and tune a closed-loop control algorithm
  4. Integrate sensing and actuation in real time
  5. Evaluate system performance through experiments

4

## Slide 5

Plan

Plan for the last 2 weeks

  - Fix the problems regarding the camera
  - Begin detection of ball with camera feed and make step movements.

5

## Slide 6

Progress

Work completed

- Completed tasks
  - Camera feed is fixed.
Work not completed
- Ball detection failed due to camera hardware limitations. Specifically, the lack of manual zoom.

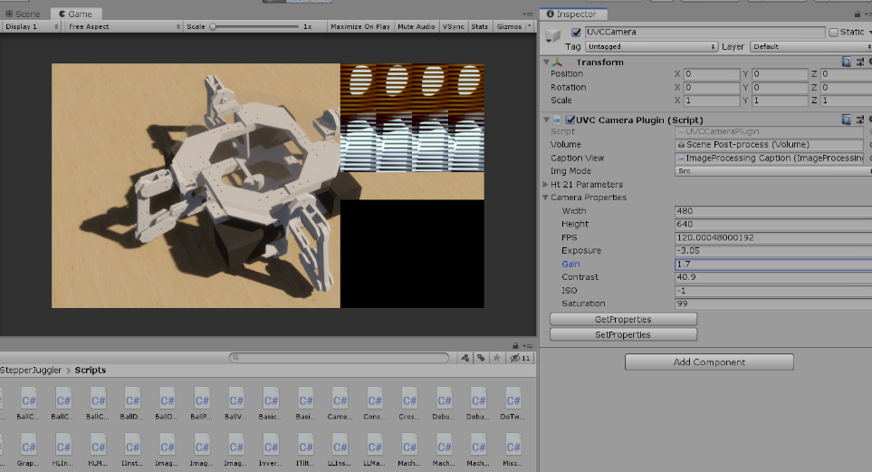
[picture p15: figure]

Before

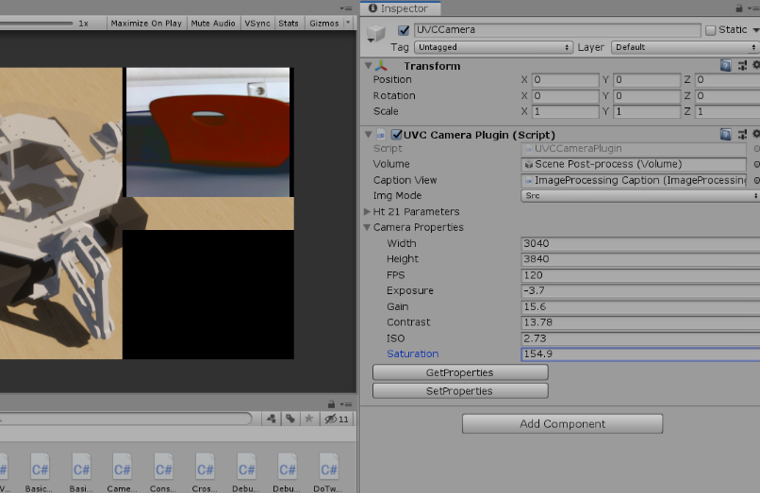
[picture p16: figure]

After

6

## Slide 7

Plan for the next 2 weeks

Problems Faced:
  - Due to the lack of a manual zoom mechanism

7

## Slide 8

Plan for the next 2 weeks

Upcoming tasks:
  - Requested support for solving the camera issue
  - Connect all the motors to the teensy.

Expected outcomes:
  - Will be able to setup the entire connection and once the camera is fixed able to start the detection of ball.

8

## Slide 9

Extra


The feed inside the Unity

The feed inside unity after fixing


9

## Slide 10

KONTAKT


Herzlichen Dank für Ihr Interesse!

Technologie
Campus Cham
Badstraße 21
93413 Cham
www.tc-cham.de

Prof. Dr. Dmitrii Dobriborsci
Dmitrii.dobriborsci@th-deg.de

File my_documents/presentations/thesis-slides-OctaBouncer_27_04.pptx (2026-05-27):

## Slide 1

- Intelligent Robotics Lab

Octo-Bouncer : Development of a multi-actuated platform for dynamic object

Student: Anandhu Vijayan
Submission date: September 13
Supervisor: Prof. Dr. Dmitrii Dobriborsci


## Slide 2

Problem definition

- Octo-Bouncer
One of the most challenging problems in a control system is balancing a system. The Octa-Bouncer is a multi-actuated dynamic manipulation system that uses camera-based ball tracking and closed-loop control to generate corrective platform motions that stabilize and influence a bouncing ball.
- Problem statement
  - To develop a real-time robotic platform that can track, predict, and control the motion of a bouncing ball using multiple actuators and visual feedback, ensuring continuous and stable bouncing through closed-loop control.
  - This thesis is relevant because it addresses the challenge of controlling fast, unpredictable dynamic objects using real-time feedback. The system demonstrates important modern robotics skills in computer vision, control, and embedded systems.


2

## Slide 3

Problem definition

  - Scope
    - Design and build a multi-actuated platform to control a bouncing ball
    - Implement camera-based ball tracking and real-time closed-loop control
    - Integrate embedded hardware, actuators, and computer vision
    - Evaluate system performance through experiments
  - Deliverables
    - Functional hardware platform
    - Embedded control firmware
    - vision tracking software [if time constraints allows]
    - Control algorithm (e.g., PID) with experimental results
    - Documentation (thesis, CAD, code, and BOM)
  - Limitations
    - No multi-ball manipulation or juggling
    - No advanced AI/ML control unless specified
    - Limited operation in controlled indoor conditions only

3

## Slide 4

Thesis goal

- Main objective
The objective is to build a platform that can automatically keep a ball bouncing by tracking its motion with a camera and adjusting the platform in real time.
- Sub-objectives
  1. Build the hardware platform
  2. Implement camera-based ball tracking
  3. Develop and tune a closed-loop control algorithm
  4. Integrate sensing and actuation in real time
  5. Evaluate system performance through experiments

4

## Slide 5

Plan

Plan for the last 2 weeks

  - Requested support for solving the camera issue
  - Connect all the motors to the teensy.

5

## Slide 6

Progress

Work completed

- Completed tasks
  - Got the suggestion to find a new lens since the one that I have is not usable.(Order is placed)
  - Connected all the motors to the teensy.

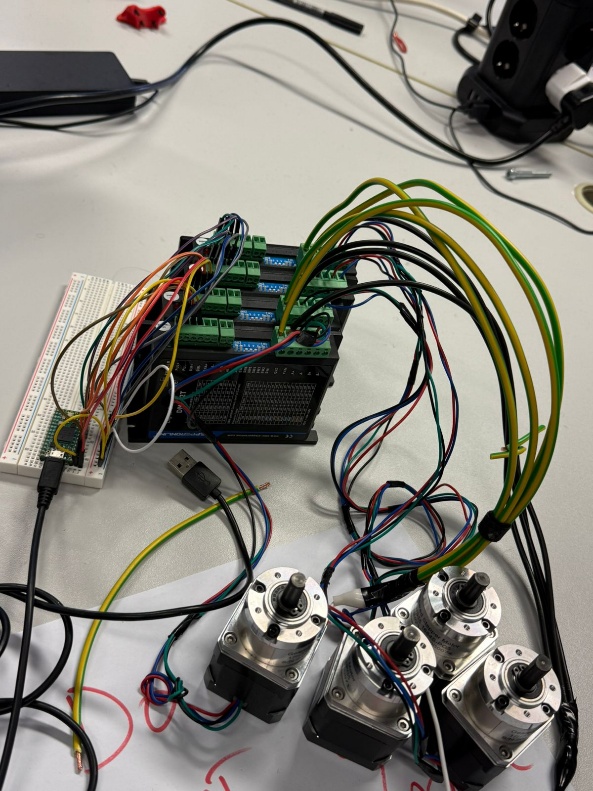
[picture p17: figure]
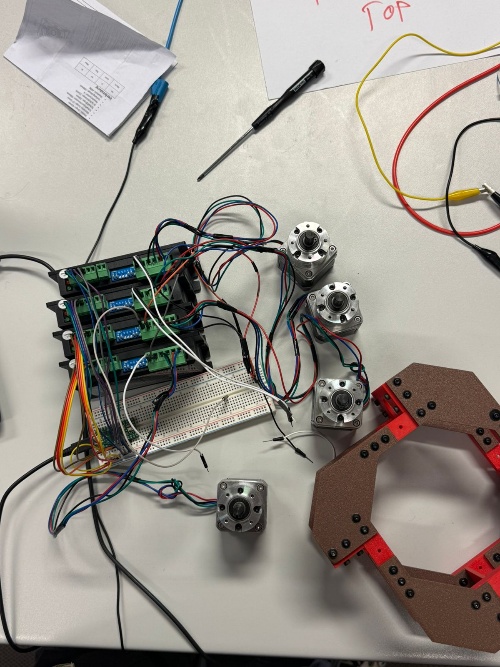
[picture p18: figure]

6

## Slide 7

Plan for the next 2 weeks

Problems Faced:
  - While making the connection the teensy got fried,
  - Conducted the continuity test and check the voltmeter reading , everything is fine.

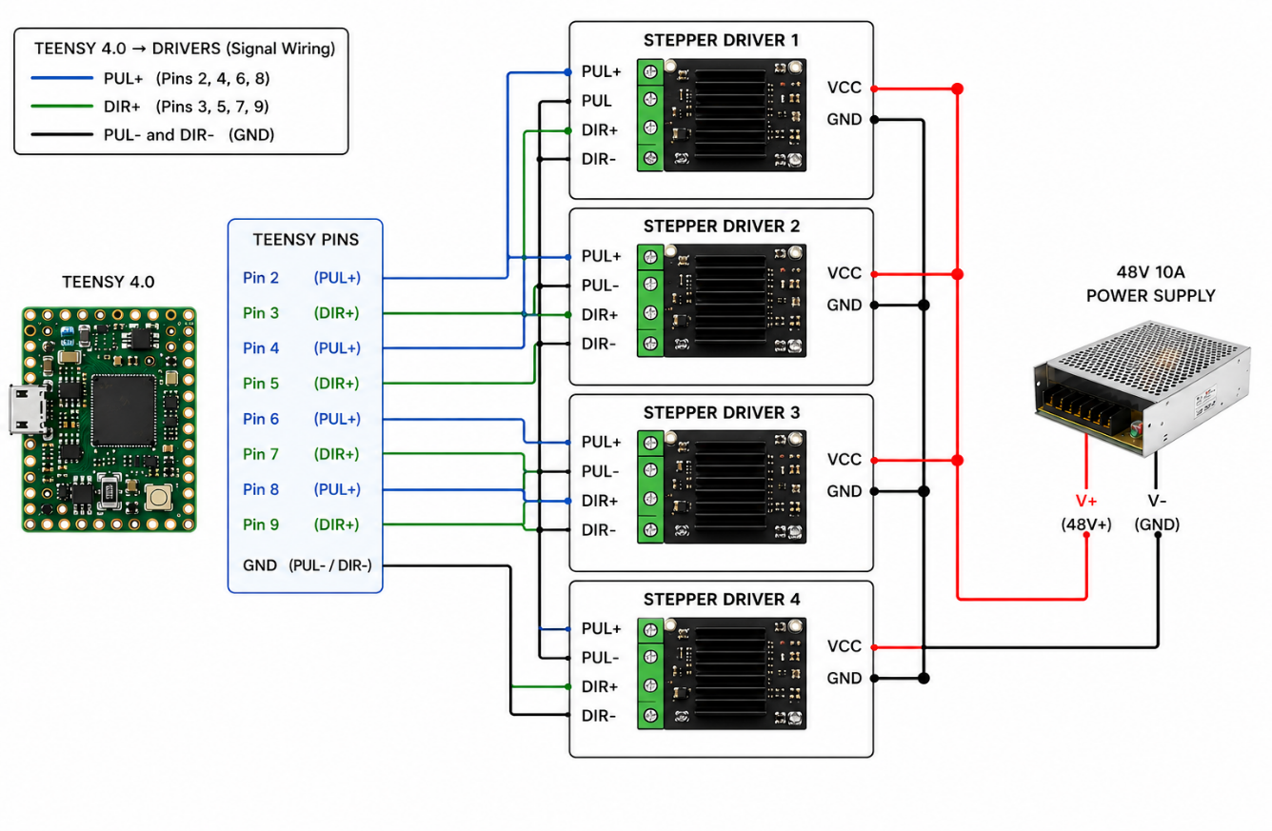
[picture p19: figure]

Connection diagram (which fried the controller)

7

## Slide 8

Plan for the next 2 weeks

Upcoming tasks:
  - Need to find the reason for the short circuit.
  - Rewire everything.
  - Successfully make the connection.
  - After the lens is delivered, need to configure that and make ball detection

Expected outcomes:
  - Successful connection, ball detection using open CV will be able to start.

8

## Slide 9

Extra


The feed inside the Unity

The feed inside unity after fixing


9

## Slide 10

KONTAKT


Herzlichen Dank für Ihr Interesse!

Technologie
Campus Cham
Badstraße 21
93413 Cham
www.tc-cham.de

Prof. Dr. Dmitrii Dobriborsci
Dmitrii.dobriborsci@th-deg.de

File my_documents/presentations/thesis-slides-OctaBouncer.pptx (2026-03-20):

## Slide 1

- Intelligent Robotics Lab

Octo-Bouncer Master Thesis

Student: Anandhu Vijayan
Supervisor: Prof. Dr. Dmitrii Dobriborsci


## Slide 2

Problem definition

- Octo-Bouncer Master Thesis – Complete Execution Plan
One of the most challenging problems in a control system is balancing a system. The Octa-Bouncer is a multi-actuated dynamic manipulation system that uses camera-based ball tracking and closed-loop control to generate corrective platform motions that stabilize and influence a bouncing ball.
- Problem statement
  - To develop a real-time robotic platform that can track, predict, and control the motion of a bouncing ball using multiple actuators and visual feedback, ensuring continuous and stable bouncing through closed-loop control.
  - This thesis is relevant because it addresses the challenge of controlling fast, unpredictable dynamic objects using real-time feedback. The system demonstrates important modern robotics skills in computer vision, control, and embedded systems.

2

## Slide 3

Problem definition

  - Scope
    - Design and build a multi-actuated platform to control a bouncing ball
    - Implement camera-based ball tracking and real-time closed-loop control
    - Integrate embedded hardware, actuators, and computer vision
    - Evaluate system performance through experiments
  - Deliverables
    - Functional hardware platform
    - Embedded control firmware
    - vision tracking software [if time constraints allows]
    - Control algorithm (e.g., PID) with experimental results
    - Documentation (thesis, CAD, code, and BOM)
  - Limitations
    - No multi-ball manipulation or juggling
    - No advanced AI/ML control unless specified
    - Limited operation in controlled indoor conditions only

3

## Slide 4

Thesis goal

- Main objective
The objective is to build a platform that can automatically keep a ball bouncing by tracking its motion with a camera and adjusting the platform in real time.
- Sub-objectives
  1. Build the hardware platform
  2. Implement camera-based ball tracking
  3. Develop and tune a closed-loop control algorithm
  4. Integrate sensing and actuation in real time
  5. Evaluate system performance through experiments

4

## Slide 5

Plan

Plan for the last 2 weeks

- Hardware Planning & Ordering
  - Finalize Bill of Materials (BOM)
  - Choose microcontroller, motors, drivers, camera, PSU
  - Compare suppliers within Germany/EU
  - Place all hardware orders
- Finding papers of similar projects

5

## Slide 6

Progress

Work completed

- Completed tasks
  - Bill of Materials (BOM) completed
  - Motor , drivers, power Supply and Camera has not yet decided as there is a confusion for that I am seeking help.
  - Found a few papers of similar projects for referencing.

Work NOT completed
- Purchasing has not yet made
Reasons:
- Decision regarding the components has not yet confirmed

6

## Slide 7

Plan for the next 2 weeks

Upcoming tasks:
  - Confirming the hardware components.
  - Placing orders
  - Learn basics of microcontroller, PID theory, Stepper basics

Expected outcomes:
  - Components purchased
  - Basics learned
  - Starts working on the project
Milestone:
  - End of the above tasks, will be able to start working on the Prototype.

7

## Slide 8

Questions, needs & support

- Help required in confirming the hardware components.

8

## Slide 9

KONTAKT


Herzlichen Dank für Ihr Interesse!

Technologie
Campus Cham
Badstraße 21
93413 Cham
www.tc-cham.de

Prof. Dr. Dmitrii Dobriborsci
Dmitrii.dobriborsci@th-deg.de

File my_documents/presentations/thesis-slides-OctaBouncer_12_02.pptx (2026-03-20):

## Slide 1

- Intelligent Robotics Lab

Octo-Bouncer : Development of a multi-actuated platform for dynamic object

Student: Anandhu Vijayan
Submission date: September 16 (approx)
Supervisor: Prof. Dr. Dmitrii Dobriborsci


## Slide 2

Problem definition

- Octo-Bouncer
One of the most challenging problems in a control system is balancing a system. The Octa-Bouncer is a multi-actuated dynamic manipulation system that uses camera-based ball tracking and closed-loop control to generate corrective platform motions that stabilize and influence a bouncing ball.
- Problem statement
  - To develop a real-time robotic platform that can track, predict, and control the motion of a bouncing ball using multiple actuators and visual feedback, ensuring continuous and stable bouncing through closed-loop control.
  - This thesis is relevant because it addresses the challenge of controlling fast, unpredictable dynamic objects using real-time feedback. The system demonstrates important modern robotics skills in computer vision, control, and embedded systems.


2

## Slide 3

Problem definition

  - Scope
    - Design and build a multi-actuated platform to control a bouncing ball
    - Implement camera-based ball tracking and real-time closed-loop control
    - Integrate embedded hardware, actuators, and computer vision
    - Evaluate system performance through experiments
  - Deliverables
    - Functional hardware platform
    - Embedded control firmware
    - vision tracking software [if time constraints allows]
    - Control algorithm (e.g., PID) with experimental results
    - Documentation (thesis, CAD, code, and BOM)
  - Limitations
    - No multi-ball manipulation or juggling
    - No advanced AI/ML control unless specified
    - Limited operation in controlled indoor conditions only

3

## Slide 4

Thesis goal

- Main objective
The objective is to build a platform that can automatically keep a ball bouncing by tracking its motion with a camera and adjusting the platform in real time.
- Sub-objectives
  1. Build the hardware platform
  2. Implement camera-based ball tracking
  3. Develop and tune a closed-loop control algorithm
  4. Integrate sensing and actuation in real time
  5. Evaluate system performance through experiments

4

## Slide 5

Plan

Plan for the last 2 weeks

  - Learn microcontroller, PID theory, Stepper basics.
  - Move motor with step commands.
  - Begin logging motor response.
  - Implement simple PID for one actuator.

5

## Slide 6

Progress

Work completed

- Completed tasks
  - The basics of stepper motor and microcontroller is still on the learning.
  - Achieved the step command movement of single motor.
  - Designing of the arms and links finished and started to 3d print it.
Work not completed
- Implementation of simple PID for one actuator.(Later understood that is not required since the PID implementation is on the lilt plate).

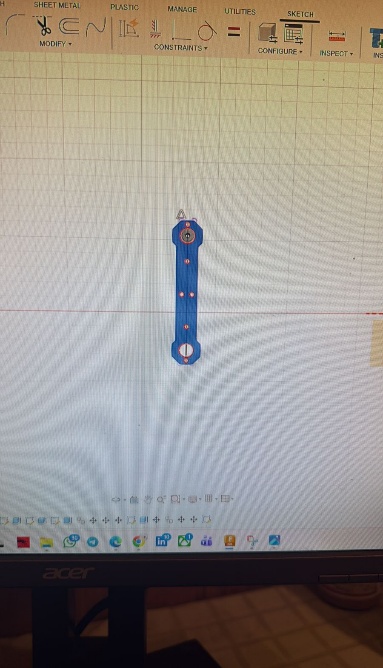
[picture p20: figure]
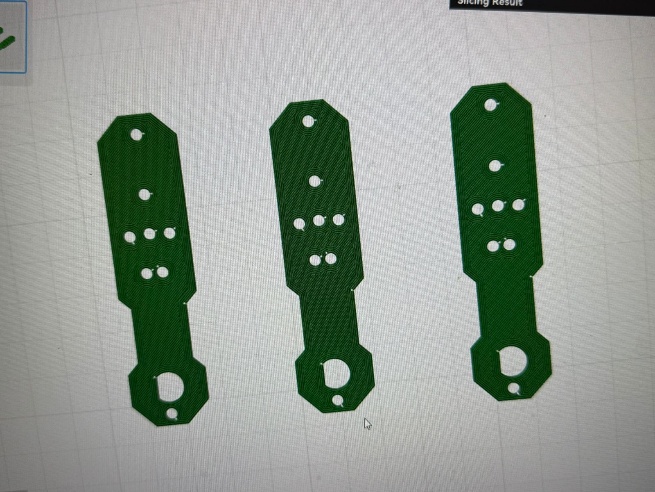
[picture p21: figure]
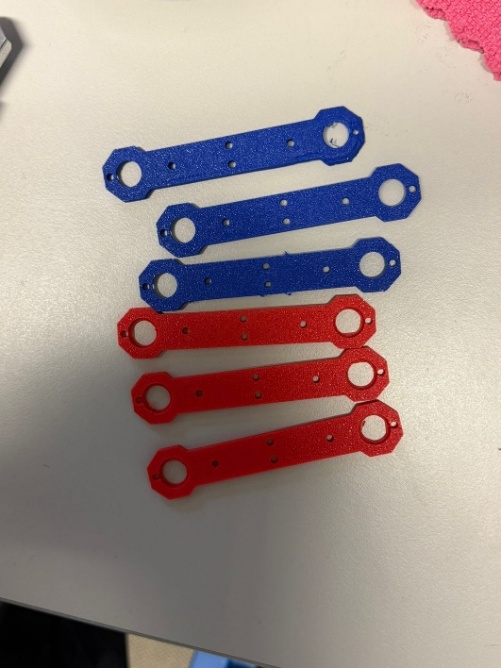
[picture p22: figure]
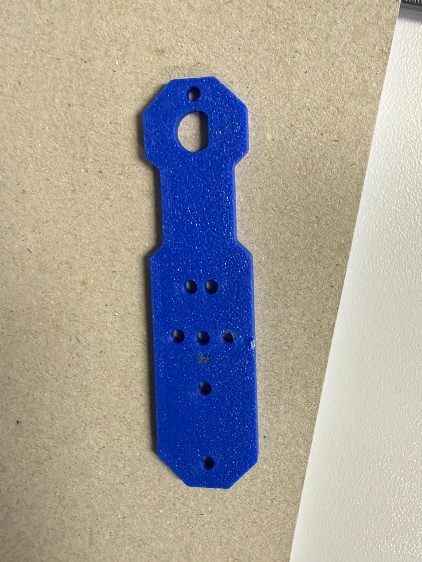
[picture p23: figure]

6

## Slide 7

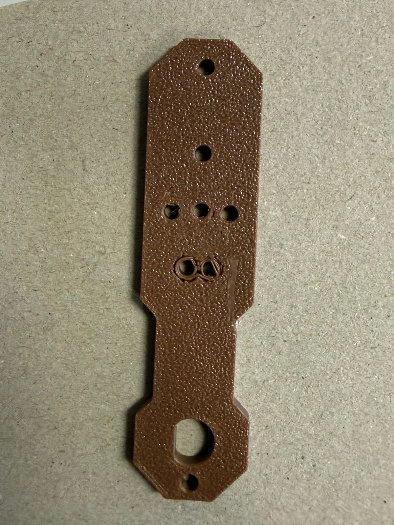
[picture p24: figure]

Problems Faced:
  - Initially the 3D printed arm was having imperfection near the holes
  - While 3 D printing some components, were not printing properly even after calibrating and cleaning the nozzle still it is a problem.
Problem Solved :
  - By increasing the wall loop, infill density and changing the pattern. This has been solved.
  - Second problem arise when 3 d printing multiple components in a single plate among that one component was facing the problem which was the print was ripping off from the build platform.

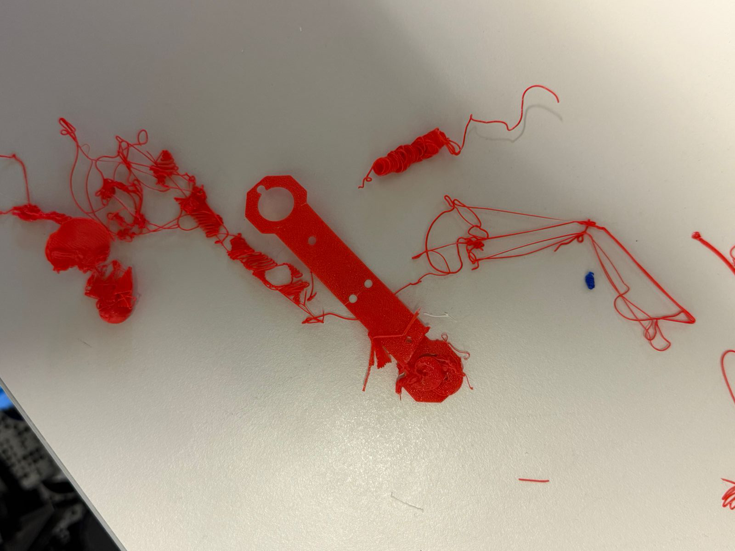
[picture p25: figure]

7

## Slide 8

Plan for the next 2 weeks

Upcoming tasks:
  - 3D print all the components.
  - Setup the camera.
  - Begin detection of ball with camera feed and make step movements.

Expected outcomes:
  - All components are 3D printed.
  - Will be able to track the ball on the camera frame.

8

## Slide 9

KONTAKT


Herzlichen Dank für Ihr Interesse!

Technologie
Campus Cham
Badstraße 21
93413 Cham
www.tc-cham.de

Prof. Dr. Dmitrii Dobriborsci
Dmitrii.dobriborsci@th-deg.de

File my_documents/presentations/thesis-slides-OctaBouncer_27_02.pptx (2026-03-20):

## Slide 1

- Intelligent Robotics Lab

Octo-Bouncer : Development of a multi-actuated platform for dynamic object

Student: Anandhu Vijayan
Submission date: September 16 (approx)
Supervisor: Prof. Dr. Dmitrii Dobriborsci


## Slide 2

Problem definition

- Octo-Bouncer
One of the most challenging problems in a control system is balancing a system. The Octa-Bouncer is a multi-actuated dynamic manipulation system that uses camera-based ball tracking and closed-loop control to generate corrective platform motions that stabilize and influence a bouncing ball.
- Problem statement
  - To develop a real-time robotic platform that can track, predict, and control the motion of a bouncing ball using multiple actuators and visual feedback, ensuring continuous and stable bouncing through closed-loop control.
  - This thesis is relevant because it addresses the challenge of controlling fast, unpredictable dynamic objects using real-time feedback. The system demonstrates important modern robotics skills in computer vision, control, and embedded systems.


2

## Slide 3

Problem definition

  - Scope
    - Design and build a multi-actuated platform to control a bouncing ball
    - Implement camera-based ball tracking and real-time closed-loop control
    - Integrate embedded hardware, actuators, and computer vision
    - Evaluate system performance through experiments
  - Deliverables
    - Functional hardware platform
    - Embedded control firmware
    - vision tracking software [if time constraints allows]
    - Control algorithm (e.g., PID) with experimental results
    - Documentation (thesis, CAD, code, and BOM)
  - Limitations
    - No multi-ball manipulation or juggling
    - No advanced AI/ML control unless specified
    - Limited operation in controlled indoor conditions only

3

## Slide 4

Thesis goal

- Main objective
The objective is to build a platform that can automatically keep a ball bouncing by tracking its motion with a camera and adjusting the platform in real time.
- Sub-objectives
  1. Build the hardware platform
  2. Implement camera-based ball tracking
  3. Develop and tune a closed-loop control algorithm
  4. Integrate sensing and actuation in real time
  5. Evaluate system performance through experiments

4

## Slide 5

Plan

Plan for the last 2 weeks

  - 3D print all the components.
  - Setup the camera.
  - Begin detection of ball with camera feed and make step movements.

5

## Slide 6

Progress

Work completed

- Completed tasks
  - Almost completed the 3 D printing.
Work not completed
- While setting up the camera with the unity, the Unity is crashing, showing runtime error.

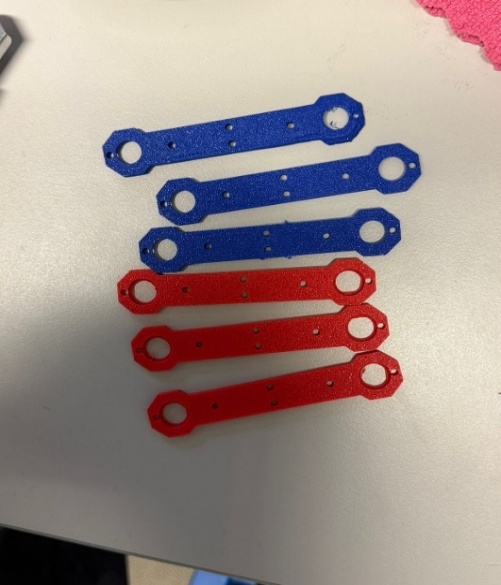
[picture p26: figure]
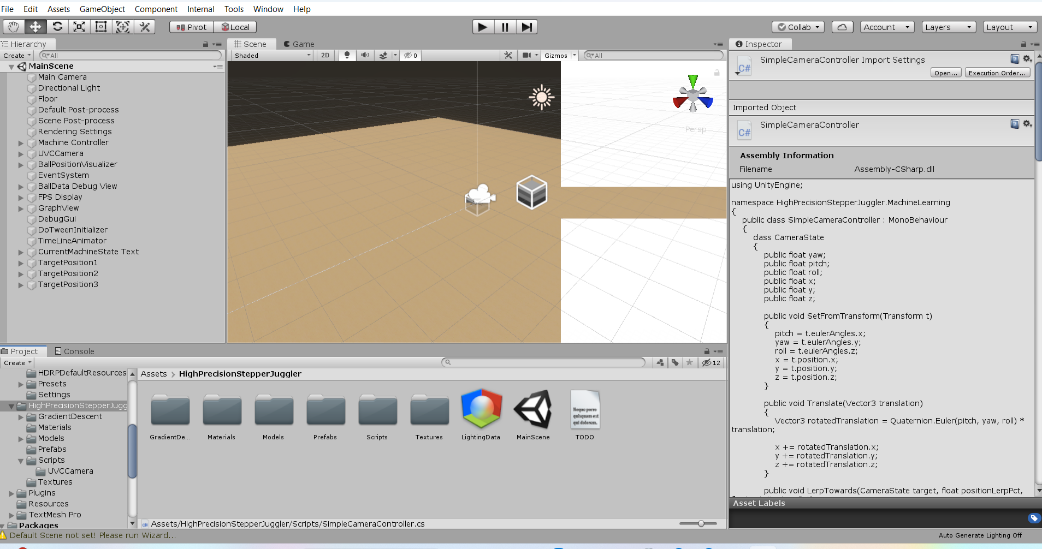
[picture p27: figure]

6

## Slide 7

Plan for the next 2 weeks


Problems Faced:
  - 3 D printer was having some malfunctions, so printing took more time than anticipated.
  - While setting up camera with the unity, Unity was crashing, it is still a problem, But I think it is because of some communication issue.
Problem Solved :
  - Cleaned the printers nozzle and the plate, think it was because of the fingerprints in the build platform.


7

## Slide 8

Plan for the next 2 weeks

Upcoming tasks:
  - Setup the camera.
  - Begin detection of ball with camera feed and make step movements.
  - Assembling the printed parts

Expected outcomes:
  - Will be able to track the ball on the camera frame.

8

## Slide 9

KONTAKT


Herzlichen Dank für Ihr Interesse!

Technologie
Campus Cham
Badstraße 21
93413 Cham
www.tc-cham.de

Prof. Dr. Dmitrii Dobriborsci
Dmitrii.dobriborsci@th-deg.de

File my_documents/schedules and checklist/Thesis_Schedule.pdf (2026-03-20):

# Octa-Bouncer Thesis Schedule (2-Week Phases)

### Phase 1 (Weeks 1–2)

Hardware Planning & Ordering: Finalize BOM, choose components, compare suppliers, place orders.

### Phase 2 (Weeks 3–4)

Beginner Foundations: Learn microcontroller basics, PWM, stepper basics, PID theory.

### Phase 3 (Weeks 5–6)

Initial Hardware Testing: Test MCU + driver + stepper, PSU tests, response logging.

### Phase 4 (Weeks 7–8)

Single-Actuator Control: Implement PID on one motor, basic camera study.

### Phase 5 (Weeks 9–10)

Mechanical Platform Design: Learn CAD, design platform + mounts.

### Phase 6 (Weeks 11–12)

Manufacturing & Assembly: 3D print/CNC parts, assemble frame + actuators.

### Phase 7 (Weeks 13–14)

Multi-Actuator Bring-Up: Test 2–4 motors, power distribution, coordinated motion.

### Phase 8 (Weeks 15–16)

Camera Integration: Test camera feed, ball tracking in OpenCV.

### Phase 9 (Weeks 17–18)

Vision + Control Integration: Map camera coords, partial closed-loop control.

### Phase 10 (Weeks 19–20)

Full Closed-Loop Control: Tune PID, stabilize bounce, test conditions.

### Phase 11 (Weeks 21–22)

Experimental Evaluation: Collect performance data + metrics.

### Phase 12 (Weeks 23–24)

Analysis & Improvements: Optimize mechanics, tracking, control.

### Phase 13 (Weeks 25–26)

Documentation Part 1: Write introduction, design, methodology.

### Phase 14 (Weeks 27–28)

Documentation Part 2: Write results, discussion, conclusion.

### Phase 15 (Weeks 29–30)

Revision & Submission: Proofread, finalize, demo, submit.

This schedule is structured for a beginner and spans until mid-August, covering hardware, integration, testing, and documentation.

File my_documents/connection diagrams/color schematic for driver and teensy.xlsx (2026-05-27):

Driver | PUL+ | PUL- | DIR+ | DIR- | GND | Vdc+
 | Teensy |  |  |  | PSU | PSU
Driver 1 | brown | Red | orange | yellow | white | grey+ red black coated
Driver 2 | brown | Red | orange | yellow | white | grey+ red black coated | Driver | DM542T Terminal | Teensy 4.0 Pin | Description
Driver 3 | green | Blue | violet | grey | white | black | All Drivers | PUL- / DIR- / ENA- | GND | Tie all negative logic pins to Teensy GND
Driver 4 | green | Blue | violet | grey | white | black | Driver 1 (X) | PUL+ (Step) | Pin 2 | Step Signal for Motor 1
 |  |  |  |  |  |  |  | DIR+ (Dir) | Pin 3 | Direction Signal for Motor 1
 |  | green = teensy GND |  |  |  |  | Driver 2 (Y) | PUL+ (Step) | Pin 4 | Step Signal for Motor 2
 |  |  |  |  |  |  |  | DIR+ (Dir) | Pin 5 | Direction Signal for Motor 2
 |  |  |  |  |  |  | Driver 3 (Z) | PUL+ (Step) | Pin 6 | Step Signal for Motor 3
 |  |  |  |  |  |  |  | DIR+ (Dir) | Pin 7 | Direction Signal for Motor 3
 |  |  |  |  |  |  | Driver 4 (E) | PUL+ (Step) | Pin 8 | Step Signal for Motor 4
 |  |  |  |  |  |  |  | DIR+ (Dir) | Pin 9 | Direction Signal for Motor 4
 |  |  |  |  |  |  | Global (Opt) | ENA+ (Enable) | Pin 10 | One pin can enable/disable all motors

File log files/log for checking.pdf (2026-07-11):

Initiating legacy licensing module

LICENSE SYSTEM [202676 9:16:34] Next license update check is after 2026-02-21T12:48:39

Built from 'HEAD' branch; Version is '2019.2.23f1 (87f4fccf3219) revision 8910076'; Using compiler version '191627012'
OS: 'Windows 10 (10.0.0) 64bit' Language: 'en' Physical Memory: 16205 MB BatchMode: 0, IsHumanControllingUs: 1, StartBugReporterOnCrash: 1, Is64bit: 1, IsPro: 0
[Package Manager] Server::Start -- Port 55833 was selected

COMMAND LINE ARGUMENTS:
C:\Program Files\Unity\Hub\Editor\2019.2.23f1\Editor\Unity.exe
-projectpath
C:\Users\91701\Desktop\Thesis\HighPrecisionStepperJuggler-master\Unity\HighPrecisio nStepperJuggler
-acceptSoftwareTermsForThisRunOnly
-useHub
-hubIPC
-cloudEnvironment
production
-licensingIpc
LicenseClient-91701
-hubSessionId
ec372e3d-f684-4f66-8f29-b0bb9d917e21 -accessToken
t_vK5tbkSTAH87JRuI334aq07RPD5yiPv0ci6vqvNOI008f
Successfully changed project path to: C:\Users\91701\Desktop\Thesis\HighPrecisionStepperJuggler-master\Unity\HighPrecisio nStepperJuggler
C:/Users/91701/Desktop/Thesis/HighPrecisionStepperJuggler-master/Unity/HighPrecisio nStepperJuggler
Using Asset Import Pipeline V1.
Loading GUID <-> Path mappings...0.001104 seconds
Loading Asset Database...0.078674 seconds
AssetDatabase consistency checks...0.056709 seconds [Package Manager] Done resolving packages in 1.21s seconds [Package Manager]
Registered 44 packages:
Packages from [https://packages.unity.com]:
com.unity.collab-proxy@1.2.16 (location: C:\Users\91701\Desktop\Thesis\HighPrecisionStepperJuggler-master\Unity\HighPrecisio nStepperJuggler\Library\PackageCache\com.unity.collab-proxy@1.2.16) com.unity.ext.nunit@1.0.0 (location: C:\Users\91701\Desktop\Thesis\HighPrecisionStepperJuggler-master\Unity\HighPrecisio nStepperJuggler\Library\PackageCache\com.unity.ext.nunit@1.0.0) com.unity.ide.rider@1.1.0 (location: C:\Users\91701\Desktop\Thesis\HighPrecisionStepperJuggler-master\Unity\HighPrecisio nStepperJuggler\Library\PackageCache\com.unity.ide.rider@1.1.0)

com.unity.ide.vscode@1.1.3 (location: C:\Users\91701\Desktop\Thesis\HighPrecisionStepperJuggler-master\Unity\HighPrecisio nStepperJuggler\Library\PackageCache\com.unity.ide.vscode@1.1.3) com.unity.test-framework@1.0.13 (location: C:\Users\91701\Desktop\Thesis\HighPrecisionStepperJuggler-master\Unity\HighPrecisio nStepperJuggler\Library\PackageCache\com.unity.test-framework@1.0.13) com.unity.textmeshpro@2.0.1 (location: C:\Users\91701\Desktop\Thesis\HighPrecisionStepperJuggler-master\Unity\HighPrecisio nStepperJuggler\Library\PackageCache\com.unity.textmeshpro@2.0.1) com.unity.render-pipelines.core@6.9.1 (location: C:\Users\91701\Desktop\Thesis\HighPrecisionStepperJuggler-master\Unity\HighPrecisio nStepperJuggler\Library\PackageCache\com.unity.render-pipelines.core@6.9.1) com.unity.shadergraph@6.9.1 (location: C:\Users\91701\Desktop\Thesis\HighPrecisionStepperJuggler-master\Unity\HighPrecisio nStepperJuggler\Library\PackageCache\com.unity.shadergraph@6.9.1) com.unity.visualeffectgraph@6.9.1-preview (location: C:\Users\91701\Desktop\Thesis\HighPrecisionStepperJuggler-master\Unity\HighPrecisio nStepperJuggler\Library\PackageCache\com.unity.visualeffectgraph@6.9.1-preview) Built-in packages:
com.unity.package-manager-ui@2.2.0 (location: C:\Program Files\Unity\Hub\Editor\2019.2.23f1\Editor\Data\Resources\PackageManager\BuiltInPack ages\com.unity.package-manager-ui)
com.unity.timeline@1.1.0 (location: C:\Program Files\Unity\Hub\Editor\2019.2.23f1\Editor\Data\Resources\PackageManager\BuiltInPack ages\com.unity.timeline)
com.unity.ugui@1.0.0 (location: C:\Program Files\Unity\Hub\Editor\2019.2.23f1\Editor\Data\Resources\PackageManager\BuiltInPack ages\com.unity.ugui)
com.unity.modules.ai@1.0.0 (location: C:\Program Files\Unity\Hub\Editor\2019.2.23f1\Editor\Data\Resources\PackageManager\BuiltInPack ages\com.unity.modules.ai)
com.unity.modules.androidjni@1.0.0 (location: C:\Program Files\Unity\Hub\Editor\2019.2.23f1\Editor\Data\Resources\PackageManager\BuiltInPack ages\com.unity.modules.androidjni)
com.unity.modules.animation@1.0.0 (location: C:\Program Files\Unity\Hub\Editor\2019.2.23f1\Editor\Data\Resources\PackageManager\BuiltInPack ages\com.unity.modules.animation)
com.unity.modules.assetbundle@1.0.0 (location: C:\Program Files\Unity\Hub\Editor\2019.2.23f1\Editor\Data\Resources\PackageManager\BuiltInPack ages\com.unity.modules.assetbundle)
com.unity.modules.audio@1.0.0 (location: C:\Program Files\Unity\Hub\Editor\2019.2.23f1\Editor\Data\Resources\PackageManager\BuiltInPack ages\com.unity.modules.audio)
com.unity.modules.cloth@1.0.0 (location: C:\Program Files\Unity\Hub\Editor\2019.2.23f1\Editor\Data\Resources\PackageManager\BuiltInPack ages\com.unity.modules.cloth)
com.unity.modules.director@1.0.0 (location: C:\Program Files\Unity\Hub\Editor\2019.2.23f1\Editor\Data\Resources\PackageManager\BuiltInPack ages\com.unity.modules.director)
com.unity.modules.imageconversion@1.0.0 (location: C:\Program

Files\Unity\Hub\Editor\2019.2.23f1\Editor\Data\Resources\PackageManager\BuiltInPack ages\com.unity.modules.imageconversion)
com.unity.modules.imgui@1.0.0 (location: C:\Program Files\Unity\Hub\Editor\2019.2.23f1\Editor\Data\Resources\PackageManager\BuiltInPack ages\com.unity.modules.imgui)
com.unity.modules.jsonserialize@1.0.0 (location: C:\Program Files\Unity\Hub\Editor\2019.2.23f1\Editor\Data\Resources\PackageManager\BuiltInPack ages\com.unity.modules.jsonserialize)
com.unity.modules.particlesystem@1.0.0 (location: C:\Program Files\Unity\Hub\Editor\2019.2.23f1\Editor\Data\Resources\PackageManager\BuiltInPack ages\com.unity.modules.particlesystem)
com.unity.modules.physics@1.0.0 (location: C:\Program Files\Unity\Hub\Editor\2019.2.23f1\Editor\Data\Resources\PackageManager\BuiltInPack ages\com.unity.modules.physics)
com.unity.modules.physics2d@1.0.0 (location: C:\Program Files\Unity\Hub\Editor\2019.2.23f1\Editor\Data\Resources\PackageManager\BuiltInPack ages\com.unity.modules.physics2d)
com.unity.modules.screencapture@1.0.0 (location: C:\Program Files\Unity\Hub\Editor\2019.2.23f1\Editor\Data\Resources\PackageManager\BuiltInPack ages\com.unity.modules.screencapture)
com.unity.modules.terrain@1.0.0 (location: C:\Program Files\Unity\Hub\Editor\2019.2.23f1\Editor\Data\Resources\PackageManager\BuiltInPack ages\com.unity.modules.terrain)
com.unity.modules.terrainphysics@1.0.0 (location: C:\Program Files\Unity\Hub\Editor\2019.2.23f1\Editor\Data\Resources\PackageManager\BuiltInPack ages\com.unity.modules.terrainphysics)
com.unity.modules.tilemap@1.0.0 (location: C:\Program Files\Unity\Hub\Editor\2019.2.23f1\Editor\Data\Resources\PackageManager\BuiltInPack ages\com.unity.modules.tilemap)
com.unity.modules.ui@1.0.0 (location: C:\Program Files\Unity\Hub\Editor\2019.2.23f1\Editor\Data\Resources\PackageManager\BuiltInPack ages\com.unity.modules.ui)
com.unity.modules.uielements@1.0.0 (location: C:\Program Files\Unity\Hub\Editor\2019.2.23f1\Editor\Data\Resources\PackageManager\BuiltInPack ages\com.unity.modules.uielements)
com.unity.modules.umbra@1.0.0 (location: C:\Program Files\Unity\Hub\Editor\2019.2.23f1\Editor\Data\Resources\PackageManager\BuiltInPack ages\com.unity.modules.umbra)
com.unity.modules.unityanalytics@1.0.0 (location: C:\Program Files\Unity\Hub\Editor\2019.2.23f1\Editor\Data\Resources\PackageManager\BuiltInPack ages\com.unity.modules.unityanalytics)
com.unity.modules.unitywebrequest@1.0.0 (location: C:\Program Files\Unity\Hub\Editor\2019.2.23f1\Editor\Data\Resources\PackageManager\BuiltInPack ages\com.unity.modules.unitywebrequest) com.unity.modules.unitywebrequestassetbundle@1.0.0 (location: C:\Program Files\Unity\Hub\Editor\2019.2.23f1\Editor\Data\Resources\PackageManager\BuiltInPack ages\com.unity.modules.unitywebrequestassetbundle) com.unity.modules.unitywebrequestaudio@1.0.0 (location: C:\Program Files\Unity\Hub\Editor\2019.2.23f1\Editor\Data\Resources\PackageManager\BuiltInPack ages\com.unity.modules.unitywebrequestaudio)

com.unity.modules.unitywebrequesttexture@1.0.0 (location: C:\Program Files\Unity\Hub\Editor\2019.2.23f1\Editor\Data\Resources\PackageManager\BuiltInPack ages\com.unity.modules.unitywebrequesttexture) com.unity.modules.unitywebrequestwww@1.0.0 (location: C:\Program Files\Unity\Hub\Editor\2019.2.23f1\Editor\Data\Resources\PackageManager\BuiltInPack ages\com.unity.modules.unitywebrequestwww)
com.unity.modules.vehicles@1.0.0 (location: C:\Program Files\Unity\Hub\Editor\2019.2.23f1\Editor\Data\Resources\PackageManager\BuiltInPack ages\com.unity.modules.vehicles)
com.unity.modules.video@1.0.0 (location: C:\Program Files\Unity\Hub\Editor\2019.2.23f1\Editor\Data\Resources\PackageManager\BuiltInPack ages\com.unity.modules.video)
com.unity.modules.vr@1.0.0 (location: C:\Program Files\Unity\Hub\Editor\2019.2.23f1\Editor\Data\Resources\PackageManager\BuiltInPack ages\com.unity.modules.vr)
com.unity.modules.wind@1.0.0 (location: C:\Program Files\Unity\Hub\Editor\2019.2.23f1\Editor\Data\Resources\PackageManager\BuiltInPack ages\com.unity.modules.wind)
com.unity.modules.xr@1.0.0 (location: C:\Program Files\Unity\Hub\Editor\2019.2.23f1\Editor\Data\Resources\PackageManager\BuiltInPack ages\com.unity.modules.xr)
Local packages:

com.unity.render-pipelines.high-definition@file:C:\Users\91701\Desktop\Thesis\HighP recisionStepperJuggler-master\Unity\ScriptableRenderPipeline-6.9.1\com.unity.render -pipelines.high-definition (location: C:\Users\91701\Desktop\Thesis\HighPrecisionStepperJuggler-master\Unity\ScriptableRe nderPipeline-6.9.1\com.unity.render-pipelines.high-definition)

[XR] No new subsystems found in resolved package list.
[Package Manager] Done registering packages in 0.05s seconds
Refreshing native plugins compatible for Editor in 1311.68 ms, found 2 plugins. Preloading 0 native plugins for Editor in 0.00 ms.
IsTimeToCheckForNewEditor: Update time 1783089012 current 1783322200 Initialize engine version: 2019.2.23f1 (87f4fccf3219)
[XR] Discovering subsystems at path C:/Program Files/Unity/Hub/Editor/2019.2.23f1/Editor/Data/Resources/UnitySubsystems
[XR] Discovering subsystems at path C:/Users/91701/Desktop/Thesis/HighPrecisionStepperJuggler-master/Unity/HighPrecisio nStepperJuggler/Assets
GfxDevice: creating device client; threaded=1
Direct3D:
Version: Direct3D 11.0 [level 11.1]
Renderer: NVIDIA GeForce RTX 3050 Laptop GPU (ID=0x25a2) Vendor:
VRAM: | 3962 MB
Driver: | 32.0.15.9186
WARNING: Shader Unsupported: 'HDRP/Lit' - Pass 'IndirectDXR' has no vertex shader WARNING: Shader Unsupported: 'HDRP/Lit' - Pass 'ForwardDXR' has no vertex shader WARNING: Shader Unsupported: 'HDRP/Lit' - Pass 'VisibilityDXR' has no vertex shader

WARNING: Shader Unsupported: 'HDRP/Lit' - All passes removed
WARNING: Shader Did you use #pragma only_renderers and omit this platform? WARNING: Shader Unsupported: 'HDRP/Unlit' - Pass 'IndirectDXR' has no vertex shader WARNING: Shader Unsupported: 'HDRP/Unlit' - Pass 'ForwardDXR' has no vertex shader WARNING: Shader Unsupported: 'HDRP/Unlit' - Pass 'VisibilityDXR' has no vertex shader
WARNING: Shader Unsupported: 'HDRP/Unlit' - All passes removed
WARNING: Shader Did you use #pragma only_renderers and omit this platform? [EnlightenBakeManager] m_Clear = false;
Initialize mono
Mono path[0] = 'C:/Program Files/Unity/Hub/Editor/2019.2.23f1/Editor/Data/Managed' Mono path[1] = 'C:/Program Files/Unity/Hub/Editor/2019.2.23f1/Editor/Data/MonoBleedingEdge/lib/mono/unityjit' Mono config path = 'C:/Program Files/Unity/Hub/Editor/2019.2.23f1/Editor/Data/MonoBleedingEdge/etc'
Using monoOptions
--debugger-agent=transport=dt_socket,embedding=1,server=y,suspend=n,address=127.0.0 .1:56960
Begin MonoManager ReloadAssembly
Registering precompiled unity dll's ...
Register platform support module: C:/Program Files/Unity/Hub/Editor/2019.2.23f1/Editor/Data/PlaybackEngines/WindowsStandaloneSup port/UnityEditor.WindowsStandalone.Extensions.dll
Register platform support module: C:/Program Files/Unity/Hub/Editor/2019.2.23f1/Editor/Data/PlaybackEngines/WebGLSupport/UnityEd itor.WebGL.Extensions.dll
Register platform support module: C:/Program Files/Unity/Hub/Editor/2019.2.23f1/Editor/Data/PlaybackEngines/MetroSupport/UnityEd itor.UWP.Extensions.dll
Registered in 0.704761 seconds.
Native extension for WebGL target not found
Native extension for WindowsStandalone target not found
Refreshing native plugins compatible for Editor in 0.45 ms, found 2 plugins. Preloading 0 native plugins for Editor in 0.00 ms.
Mono: successfully reloaded assembly
- Completed reload, in 8.425 seconds
Registering precompiled user dll's ...
Registered in 0.254906 seconds.
Platform modules already initialized, skipping
Begin MonoManager ReloadAssembly
Symbol file data-0000028481812020 doesn't match image C:\Users\91701\Desktop\Thesis\HighPrecisionStepperJuggler-master\Unity\HighPrecisio nStepperJuggler\Library\ScriptAssemblies\Assembly-CSharp.dll
Symbol file LoadedFromMemory is not a mono symbol file
Symbol file LoadedFromMemory doesn't match image C:\Users\91701\Desktop\Thesis\HighPrecisionStepperJuggler-master\Unity\HighPrecisio nStepperJuggler\Library\PackageCache\com.unity.ext.nunit@1.0.0\net35\unity-custom\n unit.framework.dll
Native extension for WebGL target not found
Native extension for WindowsStandalone target not found

Refreshing native plugins compatible for Editor in 0.51 ms, found 2 plugins. Preloading 0 native plugins for Editor in 0.00 ms.
Mono: successfully reloaded assembly
- Completed reload, in 5.992 seconds
Platform modules already initialized, skipping
Validating Project structure ... 0.009158 seconds.
Refresh: detecting if any assets need to be imported or removed ...

Hashing assets (21 files)... 0.193 seconds
file read: 0.001 seconds (0.160 MB)
wait for write: 0.000 seconds (I/O thread blocked by consumer, aka CPU bound) wait for read: 0.192 seconds (CPUT thread waiting for I/O thread, aka disk bound) hash: 0.000 seconds
----- Compute hash(es) for 21 asset(s).
----- Asset named Assets/HighPrecisionStepperJuggler/Scripts/MachineController.cs is skipped as no actual change.
----- Asset named Assets/HighPrecisionStepperJuggler/Scripts/RealMachine.cs is skipped as no actual change.
----- Asset named Assets/HighPrecisionStepperJuggler/Scripts/SerialInterface.cs is skipped as no actual change.
----- Asset named
Assets/HighPrecisionStepperJuggler/Scripts/UVCCamera/UVCCameraPlugin.cs is skipped as no actual change.

Refreshing native plugins compatible for Editor in 0.46 ms, found 2 plugins. Preloading 0 native plugins for Editor in 0.00 ms.
Refresh: detecting if any assets need to be imported or removed ...

Hashing assets (17 files)... 0.004 seconds
file read: 0.000 seconds (0.130 MB)
wait for write: 0.000 seconds (I/O thread blocked by consumer, aka CPU bound) wait for read: 0.003 seconds (CPUT thread waiting for I/O thread, aka disk bound) hash: 0.000 seconds
----- Compute hash(es) for 17 asset(s).

Updating
Assets/HighPrecisionStepperJuggler/GradientDescent/Materials/GraphGrid/GraphGrid Dotted Horizontal Top.mat - GUID: 0a35a86bdf3bc5643a25ed168f59af2b...
Launched and connected shader compiler UnityShaderCompiler.exe after 0.10 seconds done. [Time: 6224.824000 ms]
Unloading 2930 Unused Serialized files (Serialized files now loaded: 0)
System memory in use before: 442.6 MB.
System memory in use after: 442.2 MB.

Unloading 89 unused Assets to reduce memory usage. Loaded Objects now: 3629. Total: 4.974000 ms (FindLiveObjects: 0.638800 ms CreateObjectMapping: 0.206300 ms MarkObjects: 4.036500 ms DeleteObjects: 0.091600 ms)

Updating
Assets/HighPrecisionStepperJuggler/GradientDescent/Materials/GraphGrid/GraphGrid

Dotted Vertical.mat - GUID: 0f0be003017d2004499699575172baae...
done. [Time: 77.618900 ms]
Updating Assets/HighPrecisionStepperJuggler/Materials/Target Cross.mat - GUID: 288595f6260107341bdcb7b74a565c31...
done. [Time: 71.978000 ms]
Updating
Assets/HighPrecisionStepperJuggler/GradientDescent/Materials/GradientDescentDataPoi ntX.mat - GUID: 2f0110b9902dfe7408579eede0ece7e7...
done. [Time: 48.557600 ms]
Updating
Assets/HighPrecisionStepperJuggler/GradientDescent/Materials/GradientDescentViewLin eZ.mat - GUID: 3e735176b39bbcd4e90d01127e2ef18d...
done. [Time: 32.148800 ms]
Updating Assets/HighPrecisionStepperJuggler/Materials/Current Position Cross.mat -GUID: 4cd5abb034835d34ab00c1f609d44f81...
done. [Time: 38.147000 ms]
Updating
Assets/HighPrecisionStepperJuggler/GradientDescent/Materials/GradientDescentDataPoi ntZ.mat - GUID: 5a34bcc9fa5475d4e9448797075f005d...
done. [Time: 32.135900 ms]
Updating
Assets/HighPrecisionStepperJuggler/GradientDescent/Materials/GradientDescentViewLin eY.mat - GUID: 5e025214f88fc95438b34d14e5cbd818...
done. [Time: 27.863200 ms]
Updating
Assets/HighPrecisionStepperJuggler/GradientDescent/Materials/GradientDescentViewLin eX.mat - GUID: 5e88753175217cd4aab78ebe9a043313...
done. [Time: 24.642800 ms]
Updating
Assets/HighPrecisionStepperJuggler/GradientDescent/Materials/GraphGrid/GraphGrid Dotted Horizontal Bottom.mat - GUID: 716a4b61260d1be40892f8e6f71bc28e...
done. [Time: 25.550600 ms]
Updating Assets/HighPrecisionStepperJuggler/Materials/Predicted Hit Position Y.mat
- GUID: 8429bdd25d8d7dd47b5c7e4596c3eff2...
done. [Time: 38.957100 ms]
Updating
Assets/HighPrecisionStepperJuggler/GradientDescent/Materials/GraphGrid/GraphGrid Horizontal.mat - GUID: 94a20a7cca04259418ec29fb50f5ce43...
done. [Time: 25.300800 ms]
Updating
Assets/HighPrecisionStepperJuggler/GradientDescent/Materials/GradientDescentView X Tilt.mat - GUID: 99bbe0eaae88bc24b84ffb97775747a1...
done. [Time: 24.078500 ms]
Updating
Assets/HighPrecisionStepperJuggler/GradientDescent/Materials/GradientDescentDataPoi ntY.mat - GUID: c973f01ba4871bc4091aedb70bc00b29...
done. [Time: 25.200500 ms]
Updating Assets/HighPrecisionStepperJuggler/Materials/Predicted Hit Position X.mat
- GUID: caef03a443ff686478579bbb4228c3eb...
done. [Time: 24.837100 ms]

Updating
Assets/HighPrecisionStepperJuggler/GradientDescent/Materials/GraphGrid/GraphGrid Vertical.mat - GUID: d1a0b453b8370f248a8a4c8305fee127...
done. [Time: 25.080100 ms]
Updating
Assets/HighPrecisionStepperJuggler/GradientDescent/Materials/GradientDescentView Y Tilt.mat - GUID: ee06fd0fecac78447afe3eeea262a4e9...
done. [Time: 26.654700 ms]
Unloading 46 Unused Serialized files (Serialized files now loaded: 0)
System memory in use before: 378.2 MB.
System memory in use after: 378.4 MB.

Unloading 45 unused Assets to reduce memory usage. Loaded Objects now: 3629. Total: 3.293000 ms (FindLiveObjects: 0.517000 ms CreateObjectMapping: 0.176200 ms MarkObjects: 2.555600 ms DeleteObjects: 0.043500 ms)

Refreshing native plugins compatible for Editor in 5.74 ms, found 2 plugins. Preloading 0 native plugins for Editor in 0.00 ms.
Refreshing native plugins compatible for Editor in 0.68 ms, found 2 plugins. Preloading 0 native plugins for Editor in 0.00 ms.

Refresh Completed time: 7.093859s
Asset Scan time: 0.070190s
Asset Hashing: 0.003769s [132.9 KB, 34.441345 mb/s] Asset Import (Scripting) time: 0.000000s (count: 0) Post Processs Assets (Scripting) time: 0.000000s
Asset Rehashing: 0.000000s [0 B, 0.000000 mb/s]
Asset Import (Non Scripting) time: 6.804529s (count: 17) Post Process Assets (Non Scripting) time: 0.048093s Dependent Assets to Import Queue time: 0.006587s

WARNING: Shader Unsupported: 'HDRP/Unlit' - Pass 'IndirectDXR' has no vertex shader WARNING: Shader Unsupported: 'HDRP/Unlit' - Pass 'ForwardDXR' has no vertex shader WARNING: Shader Unsupported: 'HDRP/Unlit' - Pass 'VisibilityDXR' has no vertex shader
WARNING: Shader Unsupported: 'HDRP/Unlit' - All passes removed
WARNING: Shader Did you use #pragma only_renderers and omit this platform? WARNING: Shader Unsupported: 'HDRP/Lit' - Pass 'IndirectDXR' has no vertex shader WARNING: Shader Unsupported: 'HDRP/Lit' - Pass 'ForwardDXR' has no vertex shader WARNING: Shader Unsupported: 'HDRP/Lit' - Pass 'VisibilityDXR' has no vertex shader WARNING: Shader Unsupported: 'HDRP/Lit' - All passes removed
WARNING: Shader Did you use #pragma only_renderers and omit this platform?
Warming cache for 4711 main assets: 0.006109 seconds elapsed
Initializing Unity extensions:
'C:/Program
Files/Unity/Hub/Editor/2019.2.23f1/Editor/Data/UnityExtensions/Unity/UnityVR/Editor /UnityEditor.VR.dll' GUID: 4ba2329b63d54f0187bcaa12486b1b0f
Unloading 232 Unused Serialized files (Serialized files now loaded: 0)
Loaded scene 'Assets/HighPrecisionStepperJuggler/MainScene.unity'
Deserialize: | 192.480 ms

Integration: | 277.979 ms
Integration of assets: 5.939 ms
Thread Wait Time: | 28.059 ms
Total Operation Time: | 504.458 ms
System memory in use before: 93.6 MB.
System memory in use after: 94.0 MB.

Unloading 210 unused Assets to reduce memory usage. Loaded Objects now: 5879. Total: 4.055800 ms (FindLiveObjects: 0.540800 ms CreateObjectMapping: 0.141800 ms MarkObjects: 3.218900 ms DeleteObjects: 0.153600 ms)

<RI> Initialized touch support.
<RI> Initialized touch support.
<RI> Initialized touch support.
<RI> Initialized touch support. <RI> Initialized touch support. <RI> Initialized touch support.
<RI> Initializing input.
<RI> Input initialized.
[Project] Loading completed in 56.144 seconds
Project init time: | 55.150 seconds
Template init time: | 0.000 seconds
Services packages init time: | 1.360 seconds
Package Manager init time: | 0.098 seconds
Asset Database init time: | 2.052 seconds
Global illumination init time: 0.531 seconds
Assemblies load time: | 36.853 seconds
Unity extensions init time: | 0.001 seconds
Asset Database refresh time: | 7.094 seconds
Scene opening time: | 0.825 seconds
EditorUpdateCheck: Failed The requested URL returned error: 404 Not Found Unloading 70 Unused Serialized files (Serialized files now loaded: 0) System memory in use before: 403.7 MB.
System memory in use after: 404.0 MB.

Unloading 37 unused Assets to reduce memory usage. Loaded Objects now: 6443. Total: 10.700600 ms (FindLiveObjects: 1.263600 ms CreateObjectMapping: 0.522500 ms MarkObjects: 8.801500 ms DeleteObjects: 0.112200 ms)

Created GICache directory at C:/Users/91701/AppData/LocalLow/Unity/Caches/GiCache. Took: 0.080s, timestamps: [58.961 - 59.042]
Setting up 6 worker threads for Enlighten.
Thread -> id: 2860 -> priority: 1
Thread -> id: 3c30 -> priority: 1
Thread -> id: 52dc -> priority: 1 Thread -> id: 256c -> priority: 1 Thread -> id: 404c -> priority: 1 Thread -> id: 4f00 -> priority: 1 TrimDiskCacheJob: Current cache size 3mb <RI> Initialized touch support.

Reloading assemblies for play mode.
Begin MonoManager ReloadAssembly
Symbol file data-0000028467CC8D20 doesn't match image C:\Users\91701\Desktop\Thesis\HighPrecisionStepperJuggler-master\Unity\HighPrecisio nStepperJuggler\Library\ScriptAssemblies\Assembly-CSharp.dll
Symbol file LoadedFromMemory is not a mono symbol file
Symbol file LoadedFromMemory doesn't match image C:\Users\91701\Desktop\Thesis\HighPrecisionStepperJuggler-master\Unity\HighPrecisio nStepperJuggler\Library\PackageCache\com.unity.ext.nunit@1.0.0\net35\unity-custom\n unit.framework.dll
Native extension for WebGL target not found
Native extension for WindowsStandalone target not found
Refreshing native plugins compatible for Editor in 1.44 ms, found 2 plugins. Preloading 0 native plugins for Editor in 0.00 ms.
Mono: successfully reloaded assembly
- Completed reload, in 2.100 seconds
Platform modules already initialized, skipping
[SerialInterface] Available ports: COM3 UnityEngine.DebugLogHandler:Internal_Log(LogType, LogOption, String, Object) UnityEngine.DebugLogHandler:LogFormat(LogType, Object, String, Object[]) UnityEngine.Logger:Log(LogType, Object)
UnityEngine.Debug:Log(Object)
HighPrecisionStepperJuggler.SerialInterface:Awake()

(Filename: C:\build\output\unity\unity\Runtime/Export/Debug/Debug.bindings.h Line: 35)

[SerialInterface] Configured port name: COM3 UnityEngine.DebugLogHandler:Internal_Log(LogType, LogOption, String, Object) UnityEngine.DebugLogHandler:LogFormat(LogType, Object, String, Object[]) UnityEngine.Logger:Log(LogType, Object)
UnityEngine.Debug:Log(Object)
HighPrecisionStepperJuggler.SerialInterface:Awake()

(Filename: C:\build\output\unity\unity\Runtime/Export/Debug/Debug.bindings.h Line: 35)

Loaded scene 'Temp/__Backupscenes/0.backup'
Deserialize: | 26.936 ms
Integration: | 55.038 ms
Integration of assets: 0.021 ms
Thread Wait Time: | 13.319 ms
Total Operation Time: | 95.314 ms
Ball r, x, y :0.1, 240, 320 UnityEngine.DebugLogHandler:Internal_Log(LogType, LogOption, String, Object) UnityEngine.DebugLogHandler:LogFormat(LogType, Object, String, Object[]) UnityEngine.Logger:Log(LogType, Object)
UnityEngine.Debug:Log(Object) HighPrecisionStepperJuggler.ImageProcessingInstructionSender:Update()

(Filename: C:\build\output\unity\unity\Runtime/Export/Debug/Debug.bindings.h Line: 35)

Ball r, x, y :0.1, 240, 320
UnityEngine.DebugLogHandler:Internal_Log(LogType, LogOption, String, Object) UnityEngine.DebugLogHandler:LogFormat(LogType, Object, String, Object[]) UnityEngine.Logger:Log(LogType, Object)
UnityEngine.Debug:Log(Object) HighPrecisionStepperJuggler.ImageProcessingInstructionSender:Update()

(Filename: C:\build\output\unity\unity\Runtime/Export/Debug/Debug.bindings.h Line: 35)

gi::BakeBackendSwitch: Clear() active clients.
gi::BakeBackendSwitch: switching bake backend from 3 to 1.
Ball r, x, y :0.1, 240, 320 UnityEngine.DebugLogHandler:Internal_Log(LogType, LogOption, String, Object) UnityEngine.DebugLogHandler:LogFormat(LogType, Object, String, Object[]) UnityEngine.Logger:Log(LogType, Object)
UnityEngine.Debug:Log(Object) HighPrecisionStepperJuggler.ImageProcessingInstructionSender:Update()

(Filename: C:\build\output\unity\unity\Runtime/Export/Debug/Debug.bindings.h Line: 35)

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

(Filename: C:\build\output\unity\unity\Runtime/Export/Debug/Debug.bindings.h Line: 35)

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

(Filename: C:\build\output\unity\unity\Runtime/Export/Debug/Debug.bindings.h Line: 35)

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

HighPrecisionStepperJuggler.ImageProcessingInstructionSender:Update()

(Filename: C:\build\output\unity\unity\Runtime/Export/Debug/Debug.bindings.h Line: 35)

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

(Filename: C:\build\output\unity\unity\Runtime/Export/Debug/Debug.bindings.h Line: 35)

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

(Filename: C:\build\output\unity\unity\Runtime/Export/Debug/Debug.bindings.h Line: 35)
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

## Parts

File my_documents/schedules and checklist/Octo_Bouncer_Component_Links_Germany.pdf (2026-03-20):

# Octo-Bouncer Thesis – Component Purchase Links (Germany/EU)

## Teensy 4.0 Microcontroller

Antratek Germany: https://www.antratek.de/manufacturer/pjrc-teensy-microcontroller-modules Mouser Germany: https://www.mouser.de/c/?q=teensy

## Stepper Driver – StepperOnline DM442S

StepperOnline EU Store: https://www.omc-stepperonline.com/
Cloudray EU Alternative: https://www.cloudraylaser.com/

## NEMA 17 Stepper Motor with 5:1 Planetary Gearbox

StepperOnline Geared Motors: https://www.omc-stepperonline.com/ SkyMotor EU: https://www.skysmotor.com/

## 48V 8A Power Supply

Meanwell 48V PSU (EU): https://www.meanwell-web.com/
Amazon Germany (48V 8A): https://www.amazon.de/

## e-con Systems See3CAM_CU135 USB Camera

e-con Systems Official Store (EU shipping): https://www.e-consystems.com/

Note: Prices and availability may vary. Always verify voltage, current, and compatibility before ordering. This list is prepared for academic thesis prototyping in Germany.

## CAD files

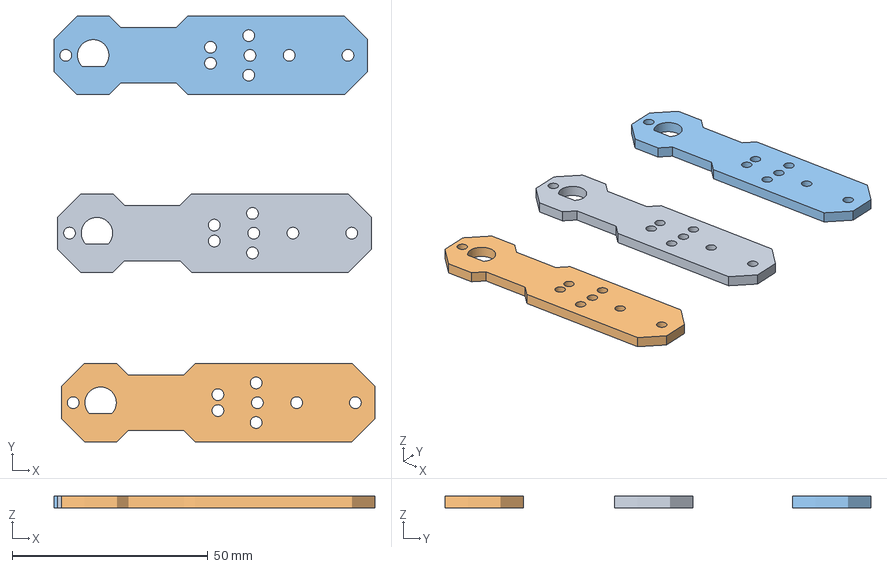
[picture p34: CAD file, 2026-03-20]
stl files/3d file/lower_arm_1_body1.3mf
81.9 x 108.6 x 3.00 mm
lower_arm_1_body1.stl x 3

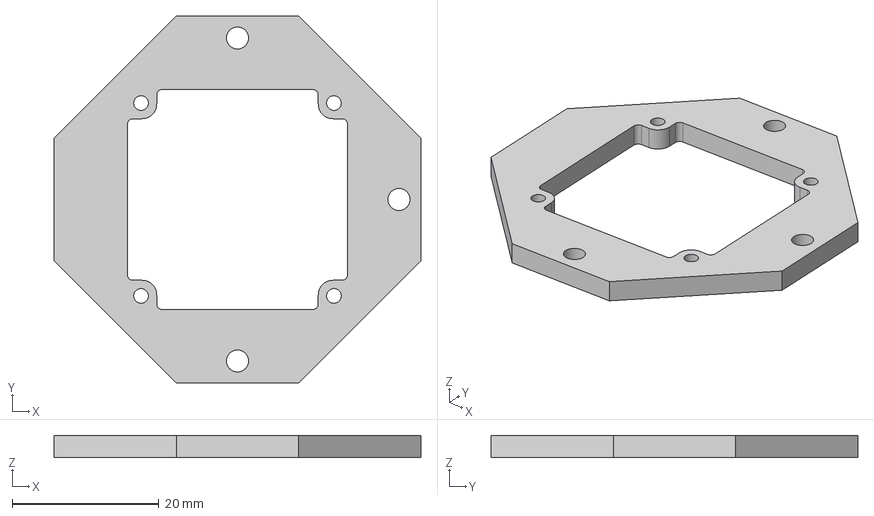
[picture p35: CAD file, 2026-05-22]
stl files/camera frame.step
50.0 x 50.0 x 3.00 mm

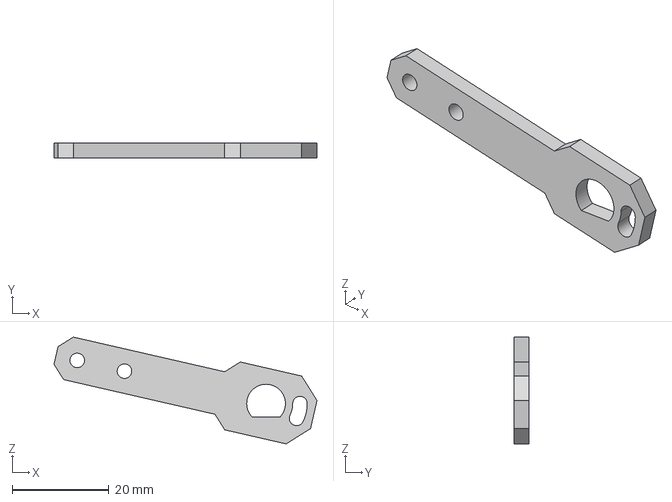
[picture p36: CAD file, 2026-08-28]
stl files/upper joint/dcut support.step
54.3 x 3.00 x 22.1 mm

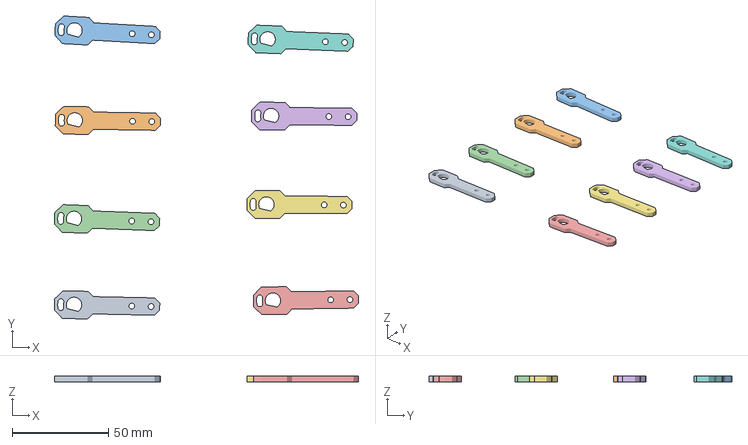
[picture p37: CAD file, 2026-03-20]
stl files/3d file/lowerarm1Body5 and body 4.3mf
158.0 x 157.4 x 3.00 mm
lowerarm1Body5.stl x 4
lowerarm1body4.stl x 4

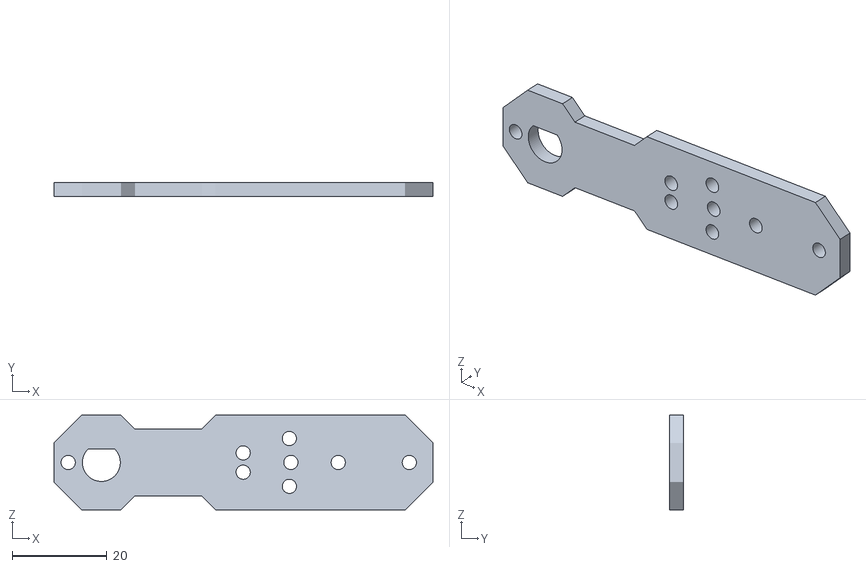
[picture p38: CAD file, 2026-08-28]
stl files/upper joint/Body1 D cut.stl
80.0 x 3.00 x 20.0

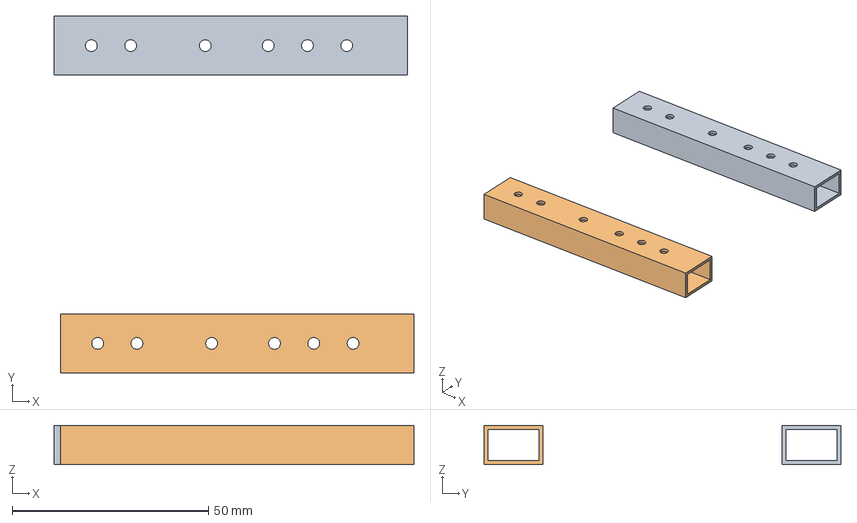
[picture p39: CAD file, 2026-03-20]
stl files/3d file/aluminiumprofile_Body1.3mf
91.6 x 90.8 x 10.0 mm
aluminiumprofile_Body1.stl x 2

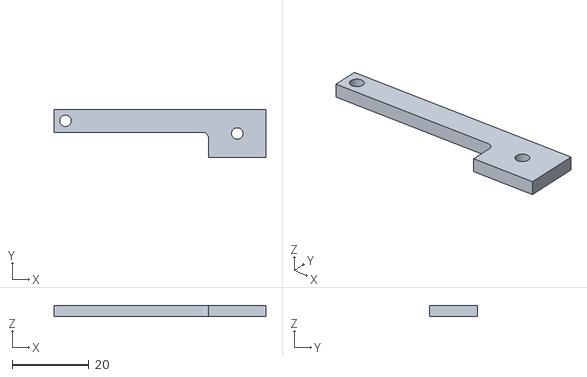
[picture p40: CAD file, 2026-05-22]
stl files/camera holder 1.stl
55.3 x 12.6 x 3.00

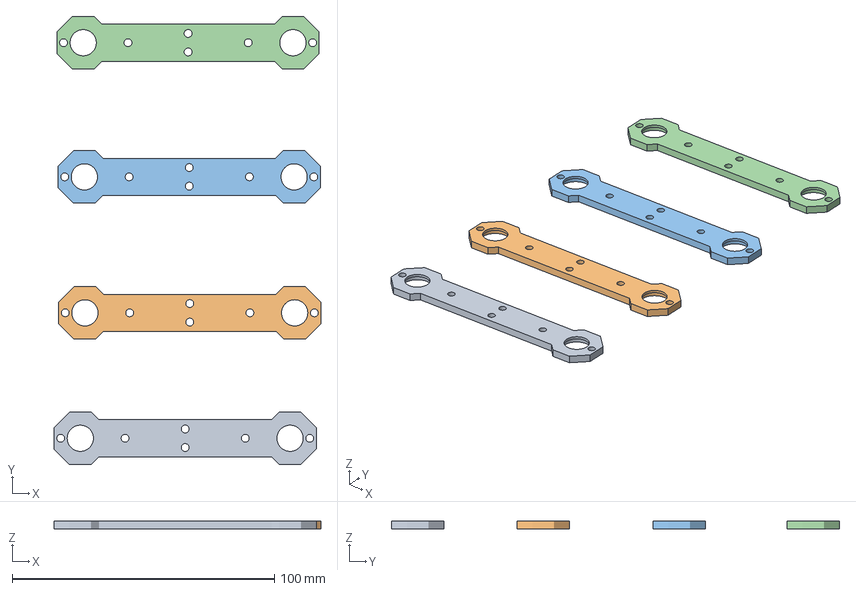
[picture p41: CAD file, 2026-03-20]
stl files/3d file/upperarm4_body_2.3mf
101.7 x 170.9 x 3.00 mm
upperarm4_body_2.stl x 4

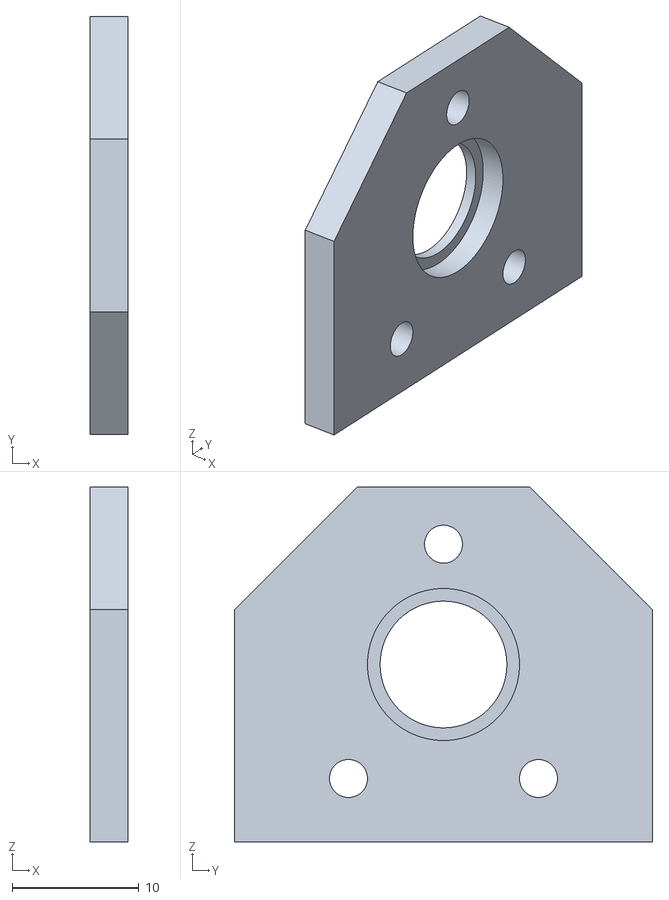
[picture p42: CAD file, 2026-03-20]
stl files/plate_Body3.stl
3.00 x 33.0 x 28.0

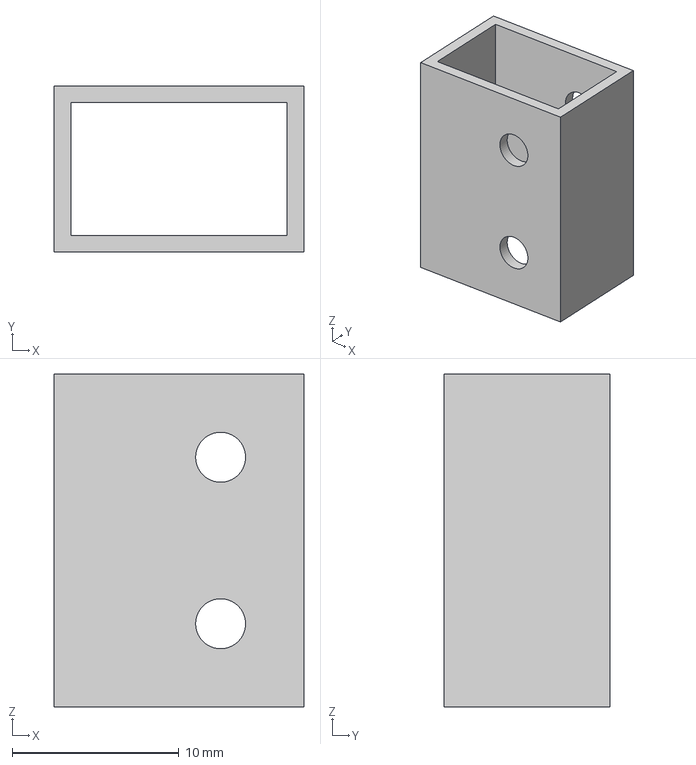
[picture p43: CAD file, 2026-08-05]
stl files/upper joint/HighPrecisionStepperJuggler.step
15.0 x 10.0 x 20.0 mm

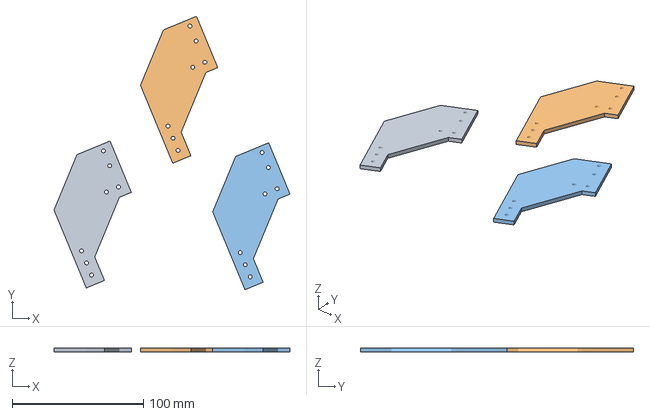
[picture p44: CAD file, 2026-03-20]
stl files/3d file/plate1_Body1.3mf
179.6 x 208.2 x 3.00 mm
plate1_Body1.stl x 3

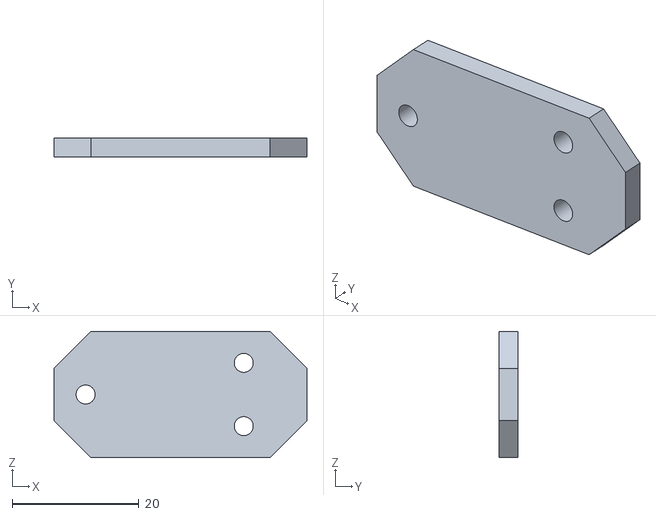
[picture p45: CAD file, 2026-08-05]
stl files/upper joint/Componentx8.stl
40.0 x 3.00 x 20.0

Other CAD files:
stl files/HighPrecisionStepperJuggler.step
stl files/upper joint/lower arm D cut.step
stl files/upperlink_Body2.stl
stl files/3d file/upperarm_4_body_1.3mf
stl files/upper joint/Component15x4.stl
stl files/upperlink_Body17.stl
Design/HighPrecisionStepperJuggler.f3d
Design/arm design.f3d
stl files/3d file/aluminium_profile_1Body5.3mf
stl files/3d file/lowerarm1Body5.3mf
stl files/3d file/lowerarm_1_Body11.3mf
stl files/3d file/plate1_Body12.3mf
stl files/3d file/plateconnector_Body3.3mf
stl files/Body2.stl
stl files/aluminium_profile_1Body5.stl
stl files/aluminiumprofile_Body1.stl
stl files/camera frame.SLDPRT
stl files/camera frame.stl
stl files/camera1_Body2.stl
stl files/camera1_Body8.stl
stl files/lower_arm_1_body1.stl
stl files/lowerarm1Body5.stl
stl files/lowerarm1body10.stl
stl files/lowerarm1body4.stl
stl files/lowerarm_1_Body11.stl
stl files/lowerarm_Body3_hidden.stl
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

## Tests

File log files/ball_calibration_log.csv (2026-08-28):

Timestamp | Label | PixelRadius | PixelX | PixelY | DistanceMm
2026-08-14 11:32:41 | origin | 119 | 52 | -76 | 20.71093
2026-08-14 11:34:11 | origin | 117 | -84 | -32 | 22.44372
2026-08-14 11:51:16 | origin | 120 | -80 | -24 | 19.86592
2026-08-14 11:53:28 | origin | 279.5256 | -2 | 30 | -38.58524
2026-08-14 11:53:31 | origin | 279.4856 | -2 | 30 | -38.57868
2026-08-14 13:15:10 | max_distance | 0.1 | 240 | 320 | 118978.2
2026-08-14 13:16:01 | max_distance | 36.34 | 81 | 30 | 249.2103
2026-08-14 14:39:31 | origin | 119 | 32 | -22 | 20.71093
2026-08-14 14:40:19 | origin | 124 | 28 | -46 | 16.6203
2026-08-14 14:40:32 | origin | 114 | 38 | -38 | 25.15539
2026-08-14 14:40:53 | origin | 116 | 78 | 20 | 23.33222
2026-08-14 14:41:45 | origin | 114 | 14 | -24 | 25.15539
2026-08-14 14:44:20 | origin | 0.1 | 240 | 320 | 118978.2
2026-08-14 14:44:43 | origin | 117 | 14 | -16 | 22.44372
2026-08-14 14:45:48 | max_distance | 94 | 22 | -14 | 47.60102
2026-08-14 14:46:15 | max_distance | 114 | 18 | -16 | 25.15539
2026-08-14 14:46:20 | origin | 118 | 16 | -14 | 21.57008
2026-08-19 16:53:43 | origin | 0.1 | 240 | 320 | 94065.73
2026-08-21 16:10:56 | origin | 279.5256 | 4 | 58 | -49.17501
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

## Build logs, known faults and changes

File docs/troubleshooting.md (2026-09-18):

# Troubleshooting, known issues and traps

| Issue | Effect | Status |
|---|---|---|
| Level trim depends on height | Levelling at the origin leaves a slope at the working height | Fixed in PyQt (`mac_trim_height`); Unity still levels at the origin |
| Unity Inspector overrides code defaults | A changed `Constants.cs` or field default appears to be ignored | By design in Unity; always check `MainScene.unity` |
| `BallData.AirborneTime` clamped to ≥ 0.1 s (Unity) | Analytical controller underestimates the lateral speed needed on short hops, so it aims short | Open |
| Analytical controller has no integrator and no rate limit (Unity) | A standing plate slope is never trained out while it is in charge | Open |
| `MaxPlateHeight = 90f` is in the wrong units (Unity) | The height clamp never engages (heights are in metres) | Open |
| Full Juggling Demo targets ±40 mm | Target lies outside the clean camera window; `BouncingStrong` exceeds arm reach | Open, inherited from original |
| Killing a host instead of closing it | Plate is left at its last tilt, which looks like lost calibration | Close normally, or run `park.py` / press **O** |
| Two programs on one COM port | Second one silently cannot send | Close the other host or the Arduino Serial Monitor |
| 3.3 V drive into 5 V opto inputs | Reduced noise margin and step-rate headroom | Hardware; see Wiring |

## When it looks like nothing is happening

The firmware is nearly silent by design: it answers `PING` with `PONG`, complains about a bad batch
marker, and says nothing else — not for a move it accepted, not for a line it could not parse. An
empty serial monitor is the normal state, not a symptom.

To tell a dead link from a dead motor, from the PyQt app's folder and with the GUI closed:

```
python hwtest.py            bare pyserial: is the board alive?
python hwtest.py --move     ... and does it move?
python workertest.py        the same, through the app's own serial worker
```

If `hwtest` passes and the plate still will not move, the fault is past the microcontroller: driver
enable, motor power, or the DM542T wiring.

## The plate sits tilted after a crash

The motors hold the last pose they were given, so anything that exits without tidying up leaves the
plate leaning. It looks exactly like lost calibration and is not. Run `python park.py` in
`pyballbalancer/`, or press **O** in Unity.

---

[← Back to the main README](../README.md) · [Hardware](hardware.md) · [Firmware](firmware.md) · [PyQt app](../pyballbalancer/README.md) · [Unity app](unity-app.md) · [Camera & motion](camera-and-motion.md) · [Troubleshooting](troubleshooting.md) · [Repository](repository.md)

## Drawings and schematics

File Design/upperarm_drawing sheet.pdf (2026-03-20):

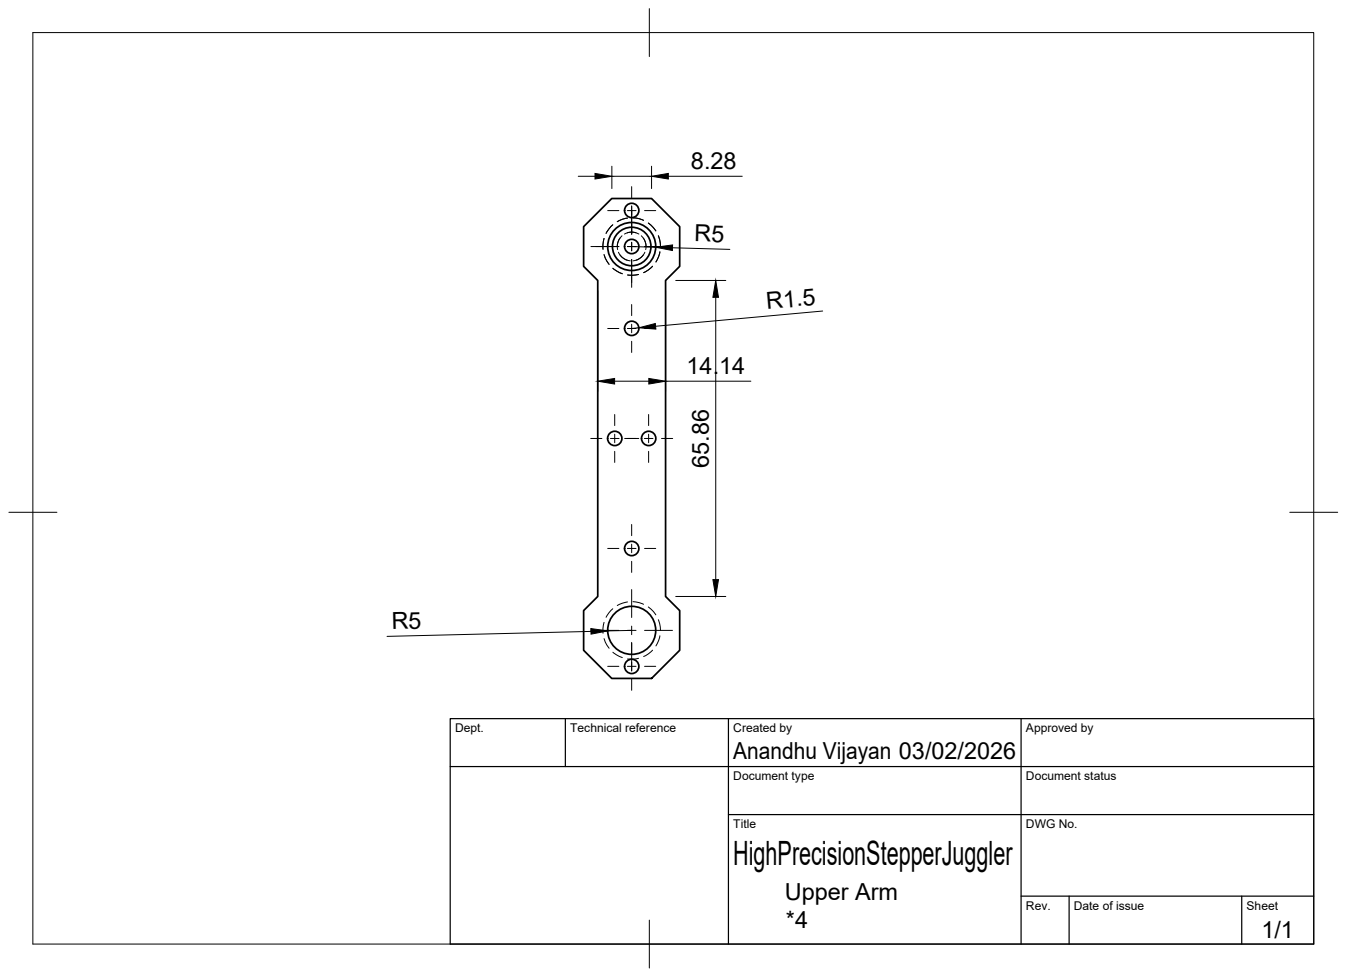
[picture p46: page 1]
Anandhu Vijayan 65.86

Dept. | Technical reference | Created by 03/02/2026 | Approved by

Document type | Document status

Title HighPrecisionStepperJuggler Upper Arm *4 | DWG No.

Rev. | Date of issue | Sheet 1/1

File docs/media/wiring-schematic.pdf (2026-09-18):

5v

35 V

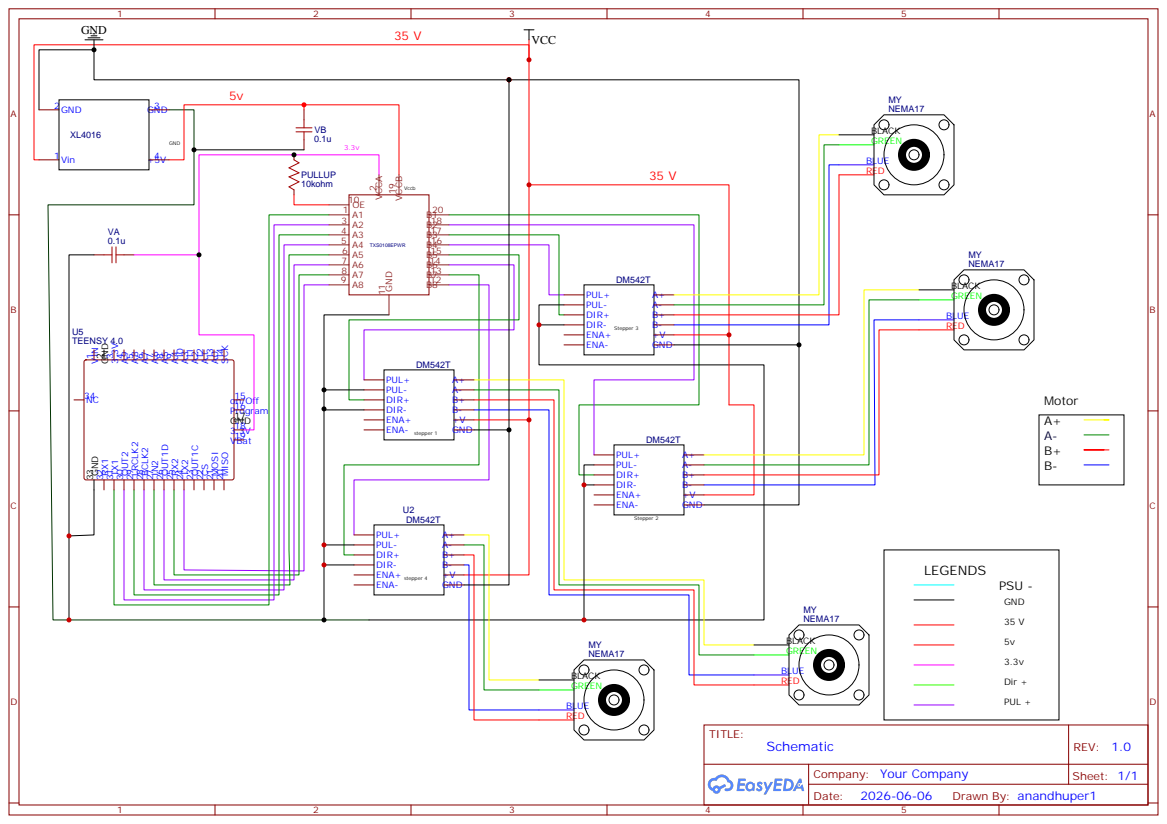
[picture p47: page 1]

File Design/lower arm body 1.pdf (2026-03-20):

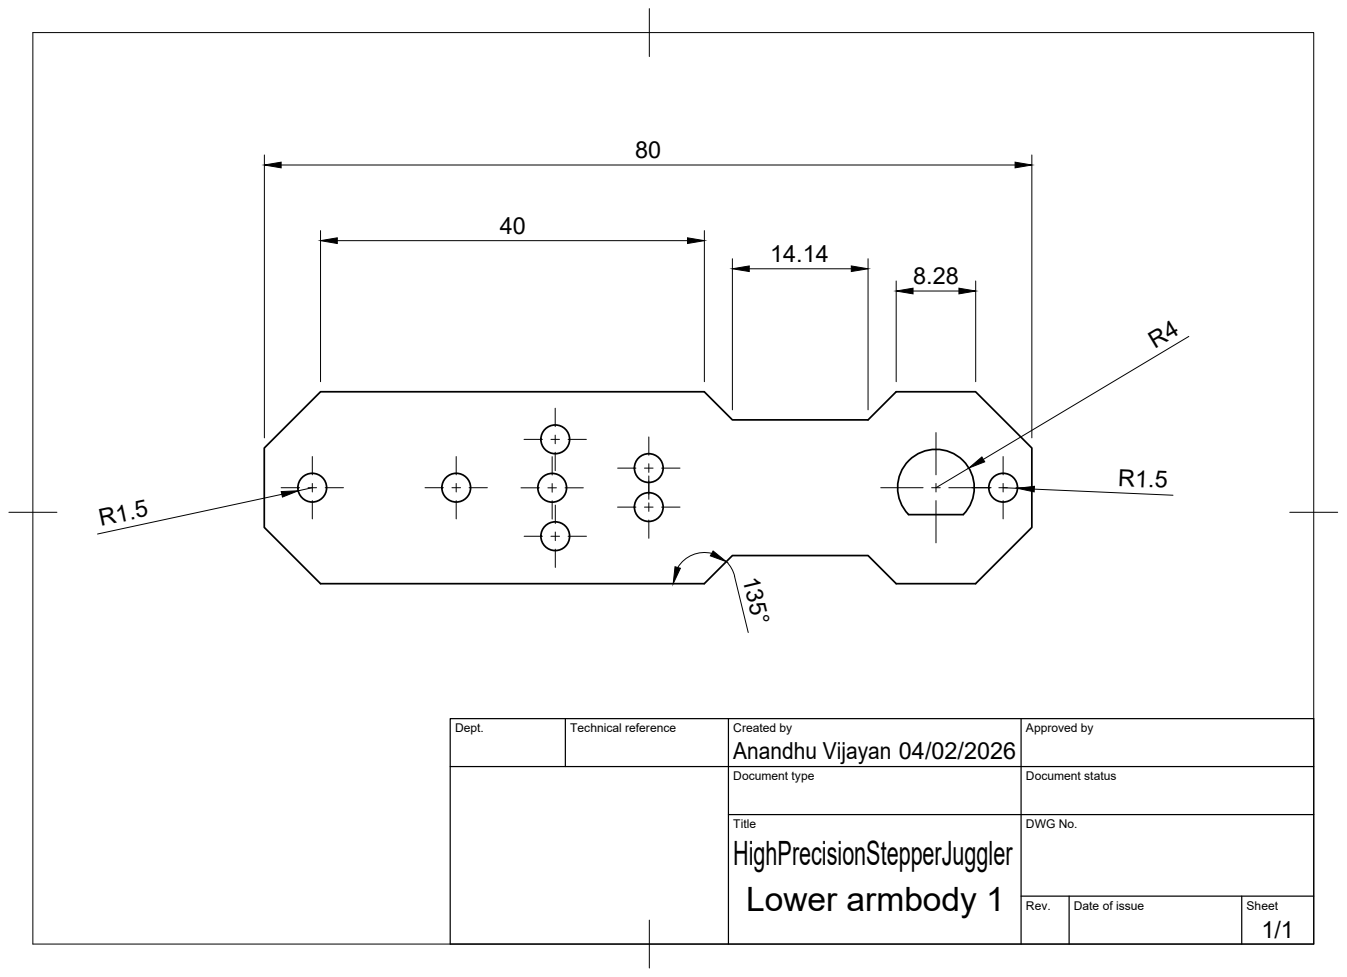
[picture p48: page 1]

Dept. | Technical reference | Created by Anandhu Vijayan 04/02/2026 | Approved by

Document type | Document status

Title HighPrecisionStepperJuggler Lower armbody 1 | DWG No.

Rev. | Date of issue | Sheet 1/1

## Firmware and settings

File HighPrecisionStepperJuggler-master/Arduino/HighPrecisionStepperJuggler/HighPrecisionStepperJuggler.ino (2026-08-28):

  /*
  HighPrecisionStepperJuggler
  Author: T-Kuhn.
  Sapporo, January, 2020. Released into the public domain.
 */

#include "Constants.h"
#include "SineStepper.h"
#include "SineStepperController.h"
#include "MoveBatch.h"

enum Mode
{
    idle,
    doingControlledMovements,
    error
};

volatile Mode currentMode = idle;
char inputBuffer[INPUT_SIZE + 1];

SineStepper sineStepper1(STEPPER1_STEP_PIN, STEPPER1_DIR_PIN, /*id:*/ 0);
SineStepper sineStepper2(STEPPER2_STEP_PIN, STEPPER2_DIR_PIN, /*id:*/ 1);
SineStepper sineStepper3(STEPPER3_STEP_PIN, STEPPER3_DIR_PIN, /*id:*/ 2);
SineStepper sineStepper4(STEPPER4_STEP_PIN, STEPPER4_DIR_PIN, /*id:*/ 3);

SineStepperController sineStepperController(/*endlessRepeat:*/ false);
IntervalTimer myTimer;

void onTimer()
{
    digitalWrite(EXECUTING_ISR_CODE, HIGH);

    switch (currentMode)
    {
    case idle:
        break;
    case doingControlledMovements:
        sineStepperController.update();
        break;
    default:
        break;
    }
    digitalWrite(EXECUTING_ISR_CODE, LOW);
}

void setup()
{
    inputBuffer[0] = '\0';
    Serial.begin(921600);
    Serial.setTimeout(1);
    myTimer.begin(onTimer, TIMER_US);

    pinMode(EXECUTING_ISR_CODE, OUTPUT);

    sineStepperController.attach(&sineStepper1);
    sineStepperController.attach(&sineStepper2);
    sineStepperController.attach(&sineStepper3);
    sineStepperController.attach(&sineStepper4);
}

void loop()
{

    if (Serial.available() > 0)
    {
        char inputChar = Serial.read();
        static int s_len;
        if (s_len >= INPUT_SIZE)
        {
            // We have received already the maximum number of characters
            // Ignore all new input until line termination occurs
        }
        else if (inputChar != '\n' && inputChar != '\r')
        {
            inputBuffer[s_len++] = inputChar;
        }
        else
        {
            // We have received a LF or CR character
            inputBuffer[s_len] = 0;

            // Liveness check. Handled before strtok(), which destroys the buffer.
            if (strcmp(inputBuffer, "PING") == 0)
            {
                Serial.println("PONG");
                memset(inputBuffer, 0, sizeof(inputBuffer));
                s_len = 0;
                return;
            }

#if VERBOSE_SERIAL_LOGGING
            Serial.print("RECEIVED MSG: ");
            Serial.println(inputBuffer);
#endif

            currentMode = idle;
            // Discard batches left over from the previous command so they can't
            // execute stale positions after the new ones finish.
            sineStepperController.clearAllMoveBatches();
            int index = 0;
            double instructionData[MAX_NUM_OF_MOVEBATCHES * 6];
            for (int i = 0; i < MAX_NUM_OF_MOVEBATCHES * 6; i++)
            {
                instructionData[i] = 0;
            }

            // Read each command
            char *command = strtok(inputBuffer, ":");
            while (command != 0)
            {
                instructionData[index] = atof(command);

                command = strtok(0, ":");
                index++;
            }

            int numOfMoveBatches = index / 6;

#if VERBOSE_SERIAL_LOGGING
            Serial.print("Parsed tokens (count=");
            Serial.print(index);
            Serial.print("): ");
            for (int t = 0; t < index; t++)
            {
                Serial.print(instructionData[t], 5);
                if (t < index - 1) Serial.print(" |");
            }
            Serial.println();

            Serial.print("Num of move batches: ");
            Serial.println(numOfMoveBatches);
#endif

            for (int i = 0; i < numOfMoveBatches; i++)
            {
                int offset = i * 6;
                MoveBatch *mb = &sineStepperController.moveBatches[i];
                
#if VERBOSE_SERIAL_LOGGING
                Serial.print("Batch "); Serial.print(i); Serial.print(" marker value: "); Serial.println(instructionData[offset], 5);
#endif

                if (instructionData[offset] > ((i + 1) * 11.0) - 0.1 && instructionData[offset] < ((i + 1) * 11) + 0.1)
                {
                    int32_t p0 = (int32_t)(PULSES_PER_REV * (instructionData[offset + 1] / (M_PI * 2)));
                    int32_t p1 = (int32_t)(PULSES_PER_REV * (instructionData[offset + 2] / (M_PI * 2)));
                    int32_t p2 = (int32_t)(PULSES_PER_REV * (instructionData[offset + 3] / (M_PI * 2)));
                    int32_t p3 = (int32_t)(PULSES_PER_REV * (instructionData[offset + 4] / (M_PI * 2)));

                    mb->addMove(/*id:*/ 0, /*pos:*/ p0);
                    mb->addMove(/*id:*/ 1, /*pos:*/ p1);
                    mb->addMove(/*id:*/ 2, /*pos:*/ p2);
                    mb->addMove(/*id:*/ 3, /*pos:*/ p3);

                    float requestedMoveDuration = instructionData[offset + 5];
                    if (requestedMoveDuration < MOVE_DURATION)
                    {
                        requestedMoveDuration = MOVE_DURATION;
                    }
                    mb->moveDuration = requestedMoveDuration;

#if VERBOSE_SERIAL_LOGGING
                    Serial.println("Marker matches expected value.");
                    Serial.print("Motor0 pulses: "); Serial.println(p0);
                    Serial.print("Motor1 pulses: "); Serial.println(p1);
                    Serial.print("Motor2 pulses: "); Serial.println(p2);
                    Serial.print("Motor3 pulses: "); Serial.println(p3);
                    Serial.print("Move duration: "); Serial.println(mb->moveDuration, 5);
#endif
                }
                else
                {
                    Serial.println("Marker did NOT match expected value - skipping batch.");
                }
            }

            sineStepperController.resetMoveBatchExecution();
            currentMode = doingControlledMovements;

            memset(inputBuffer, 0, sizeof(inputBuffer));
            s_len = 0;
        }
    }
}

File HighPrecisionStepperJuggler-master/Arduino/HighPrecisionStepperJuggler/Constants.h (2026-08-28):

/*
  Constants
  Author:
  */

#ifndef Constants_h
#define Constants_h
#include "Arduino.h"

#define STEPPER1_DIR_PIN 5
#define STEPPER1_STEP_PIN 6
#define STEPPER2_DIR_PIN 1
#define STEPPER2_STEP_PIN 2
#define STEPPER3_DIR_PIN 3
#define STEPPER3_STEP_PIN 4
#define STEPPER4_DIR_PIN 7
#define STEPPER4_STEP_PIN 8

#define NAN_ALERT_LED 25
#define EXECUTING_ISR_CODE 13

// Gear ratio: 1:5.18
// Base motor: 200 steps / rev (full step mode)

// With gear and microstepping, effective steps per revolution are:
//   full step:   200 * 1 * 5.18 = 1036
//   1/2 step:    200 * 2 * 5.18 = 2072
//   1/4 step:    200 * 4 * 5.18 = 4144
//   1/8 step:    200 * 8 * 5.18 = 8288
//   1/16 step:   200 * 16 * 5.18 = 16576
//
// This is the value currently used for the Arduino pulse scaling.
// 16576 pulses correspond to 1 full revolution of the output shaft.
// 500 pulses therefore correspond to about 0.0302 rev, or about 10.9 degrees.

#define PULSES_TO_MOVE 500 // 4000 * 16576 / 132608, keeps the same physical movement after scaling to 16576 pulses/rev
#define PULSES_PER_REV 16576 // 200 * 16 * 5.18 (gear ratio 5.18:1)
//#define MOVE_DURATION 1.0f
//#define PAUSE_DURATION 0.2f
// MOVE_DURATION is the minimum allowed move duration (sanity floor for incoming
// instructions). Unity sends 0.1s moves during balancing, so this must stay below that.
#define MOVE_DURATION 0.05f
#define PAUSE_DURATION 0.5f

//#define FREQUENCY_MULTIPLIER 0.000002f
//#define TIMER_US 2
// A 2 us interrupt was too aggressive for the sine-stepper ISR on the Teensy and could cause missed pulses.
// FREQUENCY_MULTIPLIER must equal TIMER_US expressed in seconds, otherwise moves take
// longer than the requested moveDuration. 10 us gives 5x more ISR headroom than 2 us
// while still allowing peak step rates of ~25k steps/s (one toggle per 2 ticks).
#define FREQUENCY_MULTIPLIER 0.00001f
#define TIMER_US 10

// Set to 1 to echo every received instruction, its parsed tokens and the per-motor pulse
// counts back over serial. Invaluable while bringing the link up, but during balancing Unity
// sends ~7 instructions/s and each one produces ~10 reply lines, which Unity then Debug.Logs -
// enough serial traffic and editor-console churn to add real latency and jitter to a control
// loop that only runs at 6.7Hz to begin with. PING still answers with PONG when this is 0.
#define VERBOSE_SERIAL_LOGGING 0

// NOTE: SineStepper and MoveBatch ids must be lower then MAX_NUM_OF_STEPPERS
#define MAX_NUM_OF_STEPPERS 10
#define MAX_NUM_OF_MOVEBATCHES 100

// Max input size for the list of incoming instructions
#define INPUT_SIZE 5120

#endif

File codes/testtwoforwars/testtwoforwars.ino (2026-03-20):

// Teensy 4.0 -> DM542T basic STEP/DIR test (no library)
// Works with "common-cathode" wiring: PUL-/DIR-/ENA- to GND, drive + pins from Teensy.
//
// Set your DM542T microstep DIP to match PULSES_PER_MOTOR_REV below.
// Example: if DIP says 1600 pulses/rev => use 1600.

#include <Arduino.h>

#if defined(CORE_TEENSY)
  #define WRITE_PIN digitalWriteFast
#else
  #define WRITE_PIN digitalWrite
#endif

// ---- Pins (change if you want) ----
const int STEP_PIN = 2;   // -> PUL+
const int DIR_PIN  = 3;   // -> DIR+
const int EN_PIN   = 4;   // -> ENA+ (optional)

// ---- Your setup parameters ----
const int  PULSES_PER_MOTOR_REV = 1600;  // DM542T "Pulse/rev" DIP setting (common: 400,800,1600,3200,...)
const float GEAR_RATIO = 5.18f;          // from your motor page (~5.18:1)

// Output rev pulses = motor pulses/rev * gearbox ratio
const long PULSES_PER_OUTPUT_REV = (long)(PULSES_PER_MOTOR_REV * GEAR_RATIO + 0.5f);

// Speed control (pulse period in microseconds)
// Example: 1000us period => 1000 pulses/sec
const unsigned int STEP_PERIOD_US = 500;   // adjust: smaller = faster (e.g. 500, 250, 200...)
const unsigned int STEP_HIGH_US   = 5;      // STEP high time (>=2-5us is safe)

// If your EN behavior feels inverted, flip these:
const bool ENABLE_ACTIVE_HIGH = true; // For common-cathode, ENA+ HIGH usually enables

void setEnable(bool en) {
  if (EN_PIN < 0) return;
  if (ENABLE_ACTIVE_HIGH) {
    WRITE_PIN(EN_PIN, en ? HIGH : LOW);
  } else {
    WRITE_PIN(EN_PIN, en ? LOW : HIGH);
  }
}

void stepOnce(unsigned int period_us) {
  // Rising edge is what matters; keep HIGH briefly, then LOW for rest of period
  WRITE_PIN(STEP_PIN, HIGH);
  delayMicroseconds(STEP_HIGH_US);
  WRITE_PIN(STEP_PIN, LOW);

  unsigned int lowTime = (period_us > STEP_HIGH_US) ? (period_us - STEP_HIGH_US) : 1;
  delayMicroseconds(lowTime);
}

void movePulses(long pulses, bool dir, unsigned int period_us) {
  WRITE_PIN(DIR_PIN, dir ? HIGH : LOW);
  delayMicroseconds(10); // small setup time before stepping

  for (long i = 0; i < pulses; i++) {
    stepOnce(period_us);
  }
}

void setup() {
  Serial.begin(115200);

  pinMode(STEP_PIN, OUTPUT);
  pinMode(DIR_PIN, OUTPUT);
  pinMode(EN_PIN, OUTPUT);

  WRITE_PIN(STEP_PIN, LOW);
  WRITE_PIN(DIR_PIN, LOW);

  setEnable(true);  // enable driver (optional)
  delay(200);

  Serial.println("DM542T + Teensy 4.0 step test starting...");
  Serial.print("PULSES_PER_OUTPUT_REV = ");
  Serial.println(PULSES_PER_OUTPUT_REV);
}

void loop() {
  // 2 output shaft revolution forward
  Serial.println("Forward: 2 output rev");
  movePulses(2 * PULSES_PER_OUTPUT_REV, true, STEP_PERIOD_US); // 2 *  is for two times 
  delay(800);

  // 1 output shaft revolution backward
  Serial.println("Backward: 1 output rev");
  movePulses(PULSES_PER_OUTPUT_REV, false, STEP_PERIOD_US);
  delay(800);
}

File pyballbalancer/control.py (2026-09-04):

"""Velocity estimation and the two tilt controllers.

The control loop runs on its own thread at a fixed rate rather than once per
frame, so the command rate to the microcontroller stays steady even when the
vision pipeline stutters. It always acts on the most recent detection it has
seen.

When the ball goes out of sight the plate is NOT levelled straight away. The
camera covers a band far narrower than the plate, so a ball can be sitting on
it and simply be invisible, and levelling then lets any residual slope carry it
further away — measured, that loses the ball at every escape speed tried, even
a 40 mm/s drift. Instead the plate leans back toward where the ball was last
seen for a short while, and only levels once that has failed.
"""
from __future__ import annotations

import math
import time
from collections import deque
from dataclasses import dataclass
from typing import Deque, Optional, Tuple

from PyQt5.QtCore import QThread, pyqtSignal

from vision import Detection


@dataclass
class BallState:
    x: float
    y: float
    vx: float
    vy: float
    radius: float
    t: float


class VelocityEstimator:
    """Least-squares slope over a short window.

    Differencing two consecutive frames doubles the position noise and, at
    100 fps over a few pixels of travel, that noise dominates the signal. A
    straight-line fit over N samples averages it down while still tracking a
    genuinely accelerating ball.
    """

    def __init__(self, window: int = 6) -> None:
        self._buf: Deque[Tuple[float, float, float]] = deque(maxlen=max(2, window))

    def set_window(self, window: int) -> None:
        window = max(2, int(window))
        if window != self._buf.maxlen:
            self._buf = deque(self._buf, maxlen=window)

    def reset(self) -> None:
        self._buf.clear()

    def add(self, t: float, x: float, y: float) -> None:
        self._buf.append((t, x, y))

    def estimate(self) -> Tuple[float, float]:
        n = len(self._buf)
        if n < 2:
            return 0.0, 0.0
        t0 = self._buf[0][0]
        ts = [s[0] - t0 for s in self._buf]
        mean_t = sum(ts) / n
        var_t = sum((t - mean_t) ** 2 for t in ts)
        if var_t < 1e-12:
            return 0.0, 0.0
        mean_x = sum(s[1] for s in self._buf) / n
        mean_y = sum(s[2] for s in self._buf) / n
        vx = sum((t - mean_t) * (s[1] - mean_x) for t, s in zip(ts, self._buf)) / var_t
        vy = sum((t - mean_t) * (s[2] - mean_y) for t, s in zip(ts, self._buf)) / var_t
        return vx, vy


class PIDAxis:
    """One axis, with the integral clamped so a stuck ball cannot wind it up."""

    def __init__(self) -> None:
        self.integral = 0.0
        self._last_t: Optional[float] = None

    def reset(self) -> None:
        self.integral = 0.0
        self._last_t = None

    def step(self, err: float, vel: float, kp: float, ki: float, kd: float,
             clamp: float, t: float) -> float:
        dt = 0.0 if self._last_t is None else max(0.0, t - self._last_t)
        self._last_t = t
        if ki > 0.0 and dt > 0.0:
            # The clamp is the whole anti-windup story here. Conditional
            # integration was tried and made no measurable difference: the
            # case it was meant to protect -- a ball struck hard enough to
            # saturate the tilt -- fails identically with it, without it, and
            # with ki at zero, because that ball is simply travelling faster
            # than a 3 deg plate can arrest. It is an authority limit, not a
            # windup one, so the extra mechanism earned nothing.
            self.integral = max(-clamp, min(clamp, self.integral + err * dt))
        else:
            self.integral = 0.0
        # derivative comes from the estimated velocity rather than from
        # differencing the error, which would re-introduce the noise the
        # estimator just removed
        return -(kp * err) - (ki * self.integral) - (kd * vel)


def analytical_tilt(state: BallState, tx: float, ty: float,
                    restitution: float, flight: float, gain: float) -> Tuple[float, float]:
    """Mirror-law tilt.

    Treat the bounce as a specular reflection: for the ball to leave along
    v_out having arrived along v_in, the plate normal must bisect them. The
    normal is therefore proportional to (-v_in/|v_in| + v_out/|v_out|), and
    its horizontal components give the two tilt angles.
    """
    g = 9810.0                                   # px/s² is not meaningful, so work in mm/s²
    vz_in = -g * flight / 2.0                    # downward speed at contact
    vz_out = -vz_in * max(0.05, restitution)     # upward after the bounce

    vin = (state.vx, state.vy, vz_in)
    vout = ((tx - state.x) / flight, (ty - state.y) / flight, vz_out)

    def unit(v):
        n = math.sqrt(v[0] * v[0] + v[1] * v[1] + v[2] * v[2])
        return (0.0, 0.0, 1.0) if n < 1e-9 else (v[0] / n, v[1] / n, v[2] / n)

    ix, iy, iz = unit(vin)
    ox, oy, oz = unit(vout)
    nx, ny, nz = (-ix + ox), (-iy + oy), (-iz + oz)
    if abs(nz) < 1e-6:
        return 0.0, 0.0
    # tilt about each axis is the angle between the normal and vertical
    return (math.degrees(math.atan2(nx, nz)) * gain,
            math.degrees(math.atan2(ny, nz)) * gain)
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

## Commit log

2026-03-25 camera feed fixed, made changes in the uvcc cameraplugin
2026-05-22 image detection and minor changes in code
    [HighPrecisionStepperJuggler.step, camera frame.SLDPRT, camera frame.step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]
2026-05-27 adding documents for backup
    [HighPrecisionStepperJuggler.step, camera frame.SLDPRT, camera frame.step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]
2026-07-03 logged the communication between unity and teensy
2026-07-15 motor moving corrections
2026-08-05 Add Thesis Report contents and upper joint stl files
    [Arms.step, Body1x4.stl, Body2x4.stl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]
2026-08-09 Retune UVC camera exposure/gain/saturation for sharper ball tracking
    Lower exposure (-2 -> -5) reduces motion blur further, lower gain
    (25 -> 15) compensates the added darkness without adding noise, and
    higher saturation (138 -> 160) keeps the ball color from washing out.
2026-08-14 Decouple median blur from Hough circle detection in ball tracking
    Runs median blur independently of executeHT21 so it can smooth the
    gray image even when circle detection is toggled off, and tweak
    gradient descent view materials to match.
2026-08-14 Add ball calibration logging and tune Hough circle detection threshold
    Adds keypress-triggered logging (I/X) of ball pixel radius/position at
    origin and max-operable-distance states to a CSV for FOV calibration,
    gated behind an L toggle to stop flooding the console with per-frame
    ball position logs. Also raises HoughCircles Param2 to 42 to reduce
    false-positive circle detections while limiting missed-frame flicker
    on a stationary ball.
2026-08-14 Add ball calibration logging and tune Hough circle detection threshold
    Calibrates CameraFOVInDegrees (61.6 -> 77.9) and BallHeightAtOrigin
    (78 -> 78.8) via two-point measurement using the plate's known
    Go-to-height moves, correcting a prior FOV error that mispredicted
    ball height at origin. Widens the Hough detection range (MinRadius
    12->28, MaxRadius 160->140) to track the full 0-200mm bounce height
    using the corrected calibration, lowers Param2 (42->32) since it was
    tuned against near-plate circle sizes and rejected genuine smaller
    detections near apex, and enables median blur to reduce noise at
    the now-wider size range. Also disables camera auto-exposure/
    auto-focus/auto-white-balance so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
2026-08-28 Get closed-loop balancing and juggling demos working end-to-end
    Camera/detection:
    - Fix OpenCV 4.2->4.13 rebuild losing camera controls (DSHOW pass-through)
    - Stop GetCameraProperties() reading MSMF garbage back over applied DSHOW values
    - Fix capture-thread stride bug (480x640 native vs 640x480 requested)
    - Add ball-tracking hysteresis (SelectBall) so the ceiling can't be locked onto
    - Raise MaxRadius for the new closer working origin
    Calibration:
    - Re-derive CameraFOVInDegrees/BallHeightAtOrigin from measured samples
    - Add working-origin offset mechanism (Constants.OriginHeightOffset), now 20mm
    - Add automatic tilt-sign/axis-mapping check and motor-pairing search tooling
    - Add plate backl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
    [Body1 D cut.stl, ball_calibration_log.csv, dcut support.step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]
2026-09-04 Add PyQt5 ball balancer host replacing the Unity front end
    Camera capture, ball detection, tilt control and the serial link to the
    Teensy, with every tunable live-editable from the GUI. Speaks the existing
    firmware's wire format unchanged, so either host drives the same board.
    Structure: params declares every knob once and the GUI is generated from
    that list, so a parameter cannot exist in the control maths without also
    appearing on screen. machine holds the kinematics and wire format, vision
    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
2026-09-04 Fix the ball-height camera model and extend the Unity control strategies
    FOVCalculations.CameraToPlateDistanceAtOrigin subtracted the origin offset
    where it should add: a higher plate is further from the camera, not nearer.
    Constants.BallHeightAtOrigin was wrong in the compensating direction
    (69.95 + 2 instead of 69.95 - 2), so the two cancelled exactly at the 2 mm
    offset they were fitted at and the fault stayed invisible until the offset
    was raised. At 20 mm it put the reference plane 36 mm out and reported a
    ball resting on the plate as well above the origin. Now 67.95 with a plus.
    Also here: the lateral window the camera actually sees is documented
    against the origin offset, since that w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
2026-09-04 Port the PyQt tuning into Unity and add levelling trim at origin
    The two hosts drive the same machine through the same firmware and their
    kinematics are a faithful port of each other, so with the same settings
    they must emit byte-identical wire lines. This brings Unity's settings
    across and adds the pieces it was missing.
    Level the plate at origin, the feature this was mainly for: a standing
    tilt cancelled out of every commanded pose, applied in the one chokepoint
    every instruction passes through (MachineController.SendInstructions),
    alongside the working-origin height offset and for the same reason. It is
    deliberately NOT folded into Constants.OriginMachineState, which
    Instruct() subtracts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
    [unitycheck.py]
2026-09-08 Fix ball detection, gate juggling on a centred ball, add the Unity port
    PyQt, detection: the ball was coming out as a crescent and being rejected
    as not round. Measured on live frames, 95% of its pixels passed the
    saturation floor but only 54% passed V>=50 - the ball's own value runs
    median 53, p25 17, p5 2, so nearly half of it was cut off before any
    shape gate saw it. vis_v_lo 50 -> 15 recovers the whole ball (fill 0.98,
    circularity 0.88); vis_kernel 3 -> 7 keeps it one blob rather than the
    4.1 the lower floor otherwise produces.
    PyQt, juggling: it started throwing on a timer, 1.3s after rising,
    wherever the ball happened to be. A recorded run began 250px off centre
    and nine cycles later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
    [gui.py, modes.py, modetest.py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]
2026-09-08 Add a juggle routine, supervise the ball, and level where the loop works
    Four things, all from watching runs back rather than from reasoning.
    A new Juggle routine mode: warm up on centre, walk the ball out and back
    to 20mm on each axis in turn, trace a 15mm circle, settle, land. It is
    modelled on the Unity host's Full Juggling Demo but not on its mechanism
    - that one aims each individual bounce and needs the ball's measured
    height and time of flight, neither of which this host has. The proven
    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
2026-09-08 Stop the juggle flinging the ball, and widen the Unity size cap
    Two fixes found by measuring recordings rather than reasoning.
    Send Whole Cycle At Once is now OFF, in the scene as well as the code.
    Batching all four phases into one command means ONE tilt is computed and
    then held for the entire cycle, and the ball is in contact with the plate
    for about 0.32s of it. Three degrees over 0.32s accelerates the ball to
    116 mm/s and moves it 18mm, with no chance to correct until the next
    cycle 0.47s later. Tracked on a real run: the ball crossed the camera's
    whole window in about a second and was thrown clear. Per-phase costs
    0.15s of cycle time and cuts the worst uninterrupted stretch to a
    quarte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
2026-09-08 Aim the Unity throw, and recover the ball before throwing it again
    Two changes to the Oscillating Juggling program, both aimed at the same
    problem: the camera's window is narrow, so a ball that drifts is lost long
    before the plate runs out of travel.
    AimTheThrow splits the controllers by phase - analytical on the rise, which
    is the only moment the ball leaves the plate and so the only moment a bounce
    can be aimed, and PID everywhere else, where the ball is rolling. Worth about
    3mm of correction per hop against PID's 19mm, because the hop is small.
    The supervision is the larger change. The oscillation used to settle the ball
    once and then throw for ever without looking again. Now being cent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
2026-09-16 Wire the aiming controller into the Oscillating Juggling program
    AimTheThrow shipped in the previous commit but nothing was passing it a
    controller, so aimController stayed null, the guard in Cycle() fell through
    to PID on every phase, and the feature was visible in the inspector and
    inert in practice. The strategy builder now hands it
    AnalyticalTiltController.Instance.
    Also carried along, neither of them deliberate:
    - Four .mat files where Unity re-serialised the same green with a different
    seventh decimal (0.16855851 -> 0.16855821). Float round-trip noise from
    opening the project, not a colour change.
    - Library/ cache: asset database, editor layout, hierarchy state and the
    shader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
2026-09-16 Add the recompiled Assembly-CSharp.dll
    The LFS-tracked half of the previous commit. git-lfs could not start then -
    the machine's commit charge was exhausted - and it can now, so the Unity
    build artifact goes in as its own commit rather than being left dirty.
2026-09-16 Unity rewrote every Gradient Descent View material: alpha 0 -> 1
    Committed as found, but this one is worth a second look before it is built
    on. All fourteen materials behind the telemetry panel - the X/Y/Z data
    points, the fit lines, the four GraphGrid rules, both tilt materials, both
    predicted-hit markers, and the current-position and target crosses - changed
    _UnlitColor alpha from 0 to 1 in the same pass, while Unity was open.
    The RGB is untouched in every case, so nothing about the colours changed;
    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
2026-09-16 Unity flipped the panel materials' alpha back to 0
    Reverses the previous commit's alpha 0 -> 1 on the same fourteen Gradient
    Descent View materials, again with the RGB untouched and more seventh-decimal
    float noise on the green. Seeing it flip back settles the question that
    commit left open: this is editor serialisation churn while Unity is open,
    not anybody's edit. Expect it to keep toggling until the editor is closed.
    Plus the usual Library/ cache.
2026-09-16 Rewrite the project README and bring the PyQt README up to date
    The top-level README was still the original project's text, and three of its
    facts no longer matched this repository: the camera plugin links OpenCV 4.13
    (opencv_world4130.dll), not 4.2; the Unity editor is 2019.2.23f1, not
    2019.2.6f1; and the Unity host reads the camera as 480x640 portrait. Those
    are corrected, and the original folder descriptions are kept.
    It now documents the whole project: the two independent host applications
    and why their tunings must not be cross-referenced, the repository layout,
    hardware and wiring, DM542T switch settings and their link to PULSES_PER_REV,
    the firmware protocol and its silent-failure tr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
2026-09-18 Split the README into a short front page plus docs/, and add demo clips
    The top-level README was a single long reference. It is now 94 lines: what the
    machine is, three demo clips, how to run the demo, the warning that the two
    host applications must not share tuning, and an index of everything else.
    Everything that was there is kept, moved into docs/:
    hardware.md parts, wiring, DM542T switches, power
    firmware.md uploading, the wire protocol, key constants
    unity-app.md Unity setup, strategy programs, controls, calibration
    camera-and-motion.md the field-of-view limit and the throw physics
    troubleshooting.md known issues and traps, plus what to check when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
2026-09-18 Rename the third demo clip to 'Juggling from the camera view'
2026-09-18 Add the finalised wiring schematic to the hardware page
    The EasyEDA schematic, exported at 150 dpi and clickable through to the vector
    PDF, now opens the wiring section instead of the reader being sent off to
    my_documents/ to find a diagram.
    It also settles what the level-shifting arrangement actually is. The page said
    the TXS0108E had been bypassed and the DM542T inputs driven straight from the
    Teensy at 3.3 V; the finalised drawing has the shifter in circuit, with VCCA at
    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
2026-09-18 Set the supply rail to 35 V, matching the schematic
2026-09-18 Replace the demo videos with five-second autoplaying GIFs
    The three MP4s needed a click and opened on their own page. These loop in
    place the moment the README is opened, which is what a front page wants.
    Each clip is five hand-free seconds, chosen by measuring the footage rather
    than by eye: the juggling take runs 3.6-8.6s, since a hand is on the mouse
    at the start and reaches in to the plate from 8.9s; the balancing take runs
    61.5-66.5s, the liveliest stretch with no hand in the camera view.
    All three are 10 fps, 64 colours and denoised with hqdn3d, which is what
    keeps them under a megabyte - a plain 420px GIF of the same juggling seconds
    was 1.98MB. They are not cropped tighter, because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
